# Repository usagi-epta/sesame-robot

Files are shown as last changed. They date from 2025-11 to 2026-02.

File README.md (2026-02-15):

# The Sesame Robot Project 
___







sesame-cover

___

**Greetings, from your new best friend.**

Sesame is an accessible Open-Source robotics project based on the ESP32 microcontroller system, with an emphasis on expression and movement. 
This project is designed for makers and engineers of all skill levels! Sesame offers a dynamic platform designed to start working with walking robots. 
To build a sesame robot, you will need basic soldering skills, $50-60 in hardware components, access to a 3D printer, and a basic understanding of Arduino IDE.

This repository contains the CAD design files, STL files, build and wiring guides, and the base/expanded firmware for the ESP32-based controller. 
There is also some included debugging firmware that may be helpful in getting your Sesame up and running.

## Features

*   **Quadruped Design:** Uses 8 servo motors (2 per leg) to achieve roughly 8 total degrees of freedom.
*   **Emotive Display:** Features a 128x64 OLED screen acting as a reactive face that syncs with movement.
*   **Fully Printable:** Designed entirely for 3D printing in PLA with minimal supports.
*   **Network Connectivity:** Connect to your WiFi network for remote control and API access.
*   **JSON API:** RESTful API for programmatic control from Python, JavaScript, and more.
*   **Conversational Faces:** Expressive emotion library with talk variants for voice assistant projects.
*   **Sesame Studio:** New animation composer software to easily create custom movements.
*   **Sesame Companion App:** Python application for voice control and advanced interactions.
*   **Serial CLI:** Control the robot and trigger animations via a Serial Command Line Interface or the web UI.
*   **Pre-programmed Emotes:** Includes animations for Walking, Waving, Dancing, Pointing, Resting, and more.

## Watch the launch video on YouTube

<a href="https://www.youtube.com/watch?v=1UDsWkcQZhc">thumb-youtube</a>

___

## Getting Started

Follow these steps to build your own Sesame Robot:

### 1. Gather Parts 
Check the **[Bill of Materials (BOM)](hardware/bom/README.md)** for a complete list of required electronics and hardware.
*   Microcontroller: Lolin S2 Mini (recommended for DIY builds), Sesame Distro Board V2 (included in Build Kits, pre-flashed), or ESP32-DevKitC-32E with Distro Board V1 (legacy)
*   Actuators: 8x MG90 Servos
*   Power: 5V 3A source (USB-C PD for S2 Mini and V2 Distro Board, or battery + buck converter; see BOM for the 2× 10440 Li-ion + 2× AAA holder option)

### 2. Print Parts 
Download the STLs and follow the **[Printing Guide](hardware/printing/README.md)**.
*   Designed for PLA
*   Minimal supports required

### 3. Build & Wire 
Follow the **[Build Guide](docs/build-guide/README.md)** and **[Wiring Guide](docs/wiring-guide/README.md)** to assemble the frame and connect the electronics.

### 4. Flash Firmware 
Upload the code from the **[Firmware Directory](firmware/README.md)**.
*   Requires Arduino IDE
*   Configure WiFi AP settings

### 5. Create Animations 
Use **[Sesame Studio](software/sesame-studio/README.md)** to visually design poses and sequences for your robot.

sesame-wakeup-gif

---

## Software & Firmware

### Sesame Studio
Sesame Studio is a standalone desktop application included in `software/sesame-studio/`. It allows you to:
*   Visually pose the robot using a schematic interface.
*   Generate C++ code for servo angles automatically.
*   Sequence frames into complex animations.

[**> Go to Sesame Studio**](software/sesame-studio/README.md)

sesamestudio-preview

### Sesame Companion App
The Sesame Companion App is a Python-based application that enables advanced control and interaction with your robot over your local network. It leverages the new JSON API and network mode features to provide:
*   **Voice Assistant Integration:** Control Sesame with voice commands and see real-time emotional expressions.
*   **Remote Control:** Command your robot from anywhere on your local network.
*   **Face Control:** Change expressions dynamically based on conversation or context.
*   **API Examples:** Reference implementation for building your own integrations.

The Companion App works with robots running the latest firmware with network mode enabled.

[**> Go to Sesame Companion App Repository**](https://github.com/dorianborian/sesame-companion-app)

### Firmware
The ESP32 firmware (`sesame-firmware-main.ino`) handles the kinematics, face display, and WiFi control interface.
*   **Web UI:** Control the robot from your phone via the built-in Access Point.
*   **Custom Faces:** Add your own bitmaps (guide in firmware docs).

[**> Go to Firmware Docs**](firmware/README.md)

firmware-preview

---

## Contributing

This robot is a platform for building new features, cosmetics, tools, and ideas. Since the current firmware is a basic implementation, pull requests are very welcome for:
*   Kinematics improvements
*   New animations
*   Improved Web UI/UX
*   Sensor integration (Ultrasonic, Gyro, etc.)

I would also love to see forks of this project with new hardware, software, faces, etc. Be sure to send me a message if you end up building one, and I might feature you on my website or channel!
  
---

## Sesame Complete Build Kit Pre-orders available!
I am excited to announce that, after popular demand, Sesame Complete Build Kits are now available for pre-order! 

That's right, your little robot companion just got even easier to build. Each kit includes all the components you need to build a full Sesame Robot. With the included detailed instructions, guides, and resources, this kit is perfect for both seasoned Makers and beginners. Click the image below to learn more.

<a href="https://www.doriantodd.com/sesame/kit">kits-availible</a>

---

*Created by [Dorian Todd](https://www.doriantodd.com/). Need help with your Sesame Robot? Send me a message on Discord, my username is "starphee"*

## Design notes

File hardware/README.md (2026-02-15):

# Hardware

All mechanical and electrical source files for the Sesame Robot live here. The hardware stack supports multiple build paths:

- **Hand-wired / Lolin S2 Mini build** for simple protoboard construction (recommended for DIY builds).
- **Custom Sesame Distro Board V2 build** for a professional SMD design with PD and battery support (included in Sesame Build Kits, pre-flashed).
- **Custom Sesame Distro Board V1 build** (legacy) for ESP32-DevKitC-32E stackup (phased out but still supported).

Use the sections below to jump to the files that match the version you are assembling.

## Directory Guide

| Folder | What you will find |
| --- | --- |
| [bom](bom/README.md) | Full bill of materials covering both wiring approaches, plus power budget notes and links back to the build tutorial. Start here to gather every component before printing or soldering. |
| [cad](cad/README.md) | Parametric STEP and Fusion 360 source models for every printed part. Great for remixing joint geometry or adapting the shell—just note the caution about features that may not translate across CAD packages. |
| [pcb](pcb/README.md) | Sesame Distro Board V2 (current) and V1 (legacy) schematics, layout files, Gerber files, BOM, and Pick-and-Place files. Includes ordering instructions for PCBway fabrication and assembly services. |
| [printing](printing/README.md) | Practical PLA print settings, support callouts, and image references for joint orientation and the top cover’s manual supports. |

## Getting Started

1. **Decide on a wiring strategy.** Review the comparison section in [docs/wiring-guide/README.md](../docs/wiring-guide/README.md) to choose between the protoboard and custom PCB routes. The Lolin S2 Mini build is recommended for DIY builders. If you have a Sesame Build Kit, your V2 Distro Board is already pre-flashed and ready to use.
2. **Print the shell and joints.** Follow the presets in [printing/README.md](printing/README.md) to prep the 3D files from `hardware/printing/stl`.
3. **Source electronics.** Use the line-by-line list in [bom/README.md](bom/README.md) and verify your power supply meets the 5V/3A requirement.
4. **Assemble electronics.** Reference either the hand-wiring steps or the appropriate Distro Board guide plus the wiring diagrams in `docs/wiring-guide/`.

> [!TIP]
> Keep photos of your wiring progress. They are invaluable for troubleshooting later and help when sharing build notes with the community.

## Supporting Documents

- [docs/build-guide/README.md](../docs/build-guide/README.md) for end-to-end assembly sequencing.
- [docs/wiring-guide/README.md](../docs/wiring-guide/README.md) for wiring diagrams, safety notes, and packing tips.

Improvements, remixes, and test reports are welcome, file issues or PRs with any updates you discover while building. <3

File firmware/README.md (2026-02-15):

# Sesame Robot Firmware

This document provides technical information on the firmware architecture, control logic, and hardware abstraction layers used in the Sesame Robot.

>[!NOTE]
> The firmware is now organized into a modular structure with a main entry point and specialized header files for bitmaps, movement, and web assets. This makes customization much easier and the codebase cleaner.

## Table of Contents

- [How to Flash the Firmware](#how-to-flash-the-firmware)
- [Network Configuration](#network-configuration--connectivity)
- [API Reference](#api-reference)
  - [Legacy Web Endpoints](#legacy-web-endpoints)
  - [JSON API](#json-api-recommended-for-network-clients)
  - [Python Examples](#python-api-example)
  - [JavaScript Examples](#nodejsjavascript-example)
- [Advanced Integration Examples](#advanced-integration-examples)
  - [Voice Assistant Integration](#voice-assistant-integration)
  - [Home Automation](#home-automation-integration)
- [Idle Animation System](#idle-animation-system)
- [Firmware Architecture](#firmware-architecture)
- [Technical Implementation](#technical-implementation-overview)
- [Asset Pipeline & Face Customization](#asset-pipeline--face-customization)
- [Hardware Abstraction Layer](#hardware-abstraction-layer-hal)

## How to Flash the Firmware

> [!NOTE]
> **Sesame Build Kit Users:** Your Distro Board V2 comes pre-flashed with the latest firmware. You only need to flash firmware if you want to customize it or update to a newer version.

### Prerequisites
1. **Arduino IDE** (version 2.0 or higher recommended)
2. **ESP32 Board Support**: Install via Arduino IDE's Board Manager
   - Open Arduino IDE
   - Go to **File → Preferences**
   - Add to "Additional Board Manager URLs": `https://raw.githubusercontent.com/espressif/arduino-esp32/gh-pages/package_esp32_index.json`
   - Go to **Tools → Board → Boards Manager**
   - Search for "ESP32" and install "ESP32 by Espressif Systems" (v2.0.0 or higher)
3. **Required Libraries** (install via Library Manager):
   - `ESP32Servo`
   - `Adafruit SSD1306`
   - `Adafruit GFX Library`

### Flashing Steps
1. **Connect your board** via USB to your computer
2. **Open the firmware**:
   - Open [sesame-firmware-main.ino](sesame-firmware-main.ino) in Arduino IDE
   - Make sure you have it in a folder with the same name.
   - Also include all of the .h header files.
3. **Select your board**:
   - Go to **Tools → Board**
   - For Lolin S2 Mini: Select "LOLIN S2 Mini"
   - For Sesame Distro Board V1 or V2: Select "ESP32 Dev Module"
4. **Configure board settings** (if using Lolin S2 Mini):
   - **Upload Speed**: 921600
   - **USB CDC On Boot**: "Enabled"
   - **Partition Scheme**: "Default 4MB with spiffs"
5. **Select the correct port**:
   - Go to **Tools → Port** and select your ESP32's COM port
6. **Choose your board configuration** in the code:
   - Open [sesame-firmware-main.ino](sesame-firmware-main.ino)
   - Find the pin configuration section (around line 55-65)
   - **If you built with the Lolin S2 Mini:** Uncomment the S2 Mini `servoPins` array and `I2C_SDA`/`I2C_SCL` defines. Comment out the Distro Board section.
   - **If you built with the Distro Board V1 or V2 and ESP32-DevKitC-32E:** Uncomment the Distro Board `servoPins` array and `I2C_SDA`/`I2C_SCL` defines. Comment out the S2 Mini section. (V1 and V2 use the same pin configuration)
7. **(Optional) Configure network mode**:
   - If you want the robot to connect to your WiFi network (for API access and remote control), edit the network configuration section (around line 17-22):
   ```cpp
   #define NETWORK_SSID "YourNetworkName"  // Your WiFi network name
   #define NETWORK_PASS "YourPassword"     // Your WiFi password
   #define ENABLE_NETWORK_MODE true        // Set to true to enable
   ```
   - Leave `ENABLE_NETWORK_MODE false` to use Access Point mode only
8. **Upload the firmware**:
   - Click the **Upload** button (→) in Arduino IDE
   - Wait for compilation and upload to complete
9. **Test the connection**:
   - Open Serial Monitor (**Tools → Serial Monitor**, set baud rate to 115200)
   - Reset the board - you should see startup messages and network information
   - The serial monitor provides individual motor control for testing and troubleshooting
   - **If using AP mode only**: Connect to the "Sesame-Controller-BETA" WiFi network (password: `12345678`) and navigate to any website
   - **If using network mode**: Look for the "Connected to network!" message in Serial Monitor, then access via `http://sesame-robot.local` or the displayed IP address

### Troubleshooting
- **Upload fails**: Try holding the BOOT button while uploading, or try a different USB cable
- **Port not found**: Install the appropriate USB drivers (CP210x for S2 Mini, CH340 for some ESP32 boards)
- **Compilation errors**: Verify all required libraries are installed
- **Robot not moving**: Check power supply and servo connections; increase `motorCurrentDelay` in web settings if brownouts occur
- **Can't connect to network**: 
  - Verify `ENABLE_NETWORK_MODE` is set to `true` and SSID/password are correct
  - Check Serial Monitor for connection status - look for "Connected to network!" or error messages
  - Ensure your WiFi network is 2.4GHz (ESP32 does not support 5GHz)
  - Try increasing the connection timeout in the code (currently 10 seconds / 20 attempts)
- **mDNS hostname not resolving**:
  - On Windows, install [Bonjour Print Services](https://support.apple.com/kb/DL999)
  - On Linux, ensure `avahi-daemon` is installed and running
  - Try accessing via IP address instead (check Serial Monitor for the assigned IP)
  - Some routers block mDNS traffic - check router settings or use IP address
- **API commands not working**:
  - Ensure you're sending POST requests to `/api/command` (not GET)
  - Verify `Content-Type: application/json` header is set
  - Check Serial Monitor for error messages and parsed command output
  - Test with a simple cURL command first to verify connectivity

## Firmware Architecture

The firmware is split into several key files to keep the logic organized and assets easy to manage:

- **[sesame-firmware-main.ino](sesame-firmware-main.ino)**: The main entry point containing the `setup()`, `loop()`, core system logic, network configuration, and API endpoints.
- **[face-bitmaps.h](face-bitmaps.h)**: A dedicated header for OLED face macros and raw bitmap data. Now includes extensive conversational faces for voice assistant integration.
- **[movement-sequences.h](movement-sequences.h)**: Definitions for all procedural movement and pose animations.
- **[captive-portal.h](captive-portal.h)**: Contains the HTML, CSS, and JS for the web-based remote control interface.

## Technical Implementation Overview

The firmware is built on the Arduino-ESP32 framework. Currently the firmware is running on a single-core event loop, and hardware-based PWM timers for precise motor control.

### PWM & Servo Kinematics
- **Timer Allocation**: The firmware uses `ESP32PWM::allocateTimer(n)` to reserve hardware timers 0-3. This prevents conflicts with other peripherals and ensuring high-resolution PWM signals (50Hz frequency). Due to the limited number of timers, you may experience network errors upon adding additional devices or calls to the firmware. For example, in a modded version of the robot, I tried adding two ESCs and their servo controll to the code, and the CPU ran out of internal timers and caused the captive portal to die. If you are experiencing network errors with your custom firmware, check the timer allocation.
- **Pulse Width Mapping**: Leg servos are mapped from degrees (0-180) to microseconds (732us to 2929us). This range is set to the maximum travel on most hobby servos with a 180 degree limit, but can be edited in the `servos[i].attach()` calls. If you are using motors with a larger range of motion, like 270 degree servos, you need to set the PWM mapping to a different length of microseconds. For 270 degree servos specifically I found (833us to 2167us) works.
- **Staggered Activation**: To prevent VCC rail collapse (brownout) caused by simultaneous inductive loads, the `setServoAngle` helper introduces a mandatory `motorCurrentDelay` (default 20ms) between sequential pulses. This delay should be tweaked to your power setup. If you have a strong dedicated power supply you can try setting it to zero. It can also be changed while running through the AP controller settings menu.

### Communication & Networking Stack
- **Dual-Mode WiFi**: The ESP32 can simultaneously operate in both Access Point mode (for direct connections) and Station mode (connected to an existing network) using `WiFi.mode(WIFI_AP_STA)`.
- **SoftAP & Captive Portal**: The ESP32 initializes an Access Point using `WiFi.softAP()`. A `DNSServer` listens on UDP Port 53, using a wildcard "*" redirect to map all DNS queries to the internal gateway (`192.168.4.1`).
- **mDNS Service Discovery**: The firmware broadcasts `sesame-robot.local` via Multicast DNS (mDNS) using the `ESPmDNS` library, allowing network discovery without hardcoded IP addresses.
- **RESTful API Surface**: The `WebServer` handles both legacy URL-parameter endpoints and modern JSON-based API:
  - `/cmd?go=[dir]`: Legacy movement control
  - `/cmd?pose=[name]`: Legacy pose triggers
  - `/api/status`: JSON status endpoint (GET)
  - `/api/command`: JSON command endpoint (POST) - supports face-only updates and combined face+movement commands
  - `/getSettings` / `/setSettings`: Parameter configuration
- **Face-Only Command Support**: The `/api/command` endpoint intelligently detects face-only requests (no `command` field) and updates the display without triggering movement animations.
- **Non-Blocking Control Flow**: Instead of `delay()`, the firmware uses a custom `pressingCheck(String cmd, int ms)` function. This function polls `server.handleClient()` and `dnsServer.processNextRequest()` during animation frames, allowing for real-time interruptibility (e.g., immediate stop on button release). This pressingCheck protocol can be used for motion commands like walking to play each motion only when the button is held.

### Display & Graphics Subsystem
- **I2C Bus Hardware**: Utilizes the ESP32's hardware I2C controller at 400kHz (Fast Mode) for minimal latency when pushing full-frame buffers to the SSD1306 display.
- **Memory Management (`PROGMEM`)**: Large 128x64 bitmap arrays (1024 bytes per frame) are stored in Flash memory using the `PROGMEM` attribute.
- **Macro-Based Asset Management**: The firmware uses a `FACE_LIST` macro in [face-bitmaps.h](face-bitmaps.h) to automatically register and handle new faces, reducing the boilerplate required when adding animations.
- **Rendering Pipeline**: The `updateAnimatedFace()` function manages frame rates and sequence looping outside of the main movement logic to ensure smooth visual feedback even during complex movements.
- **Dynamic WiFi Info Overlay**: The `updateWifiInfoScroll()` function composites scrolling connection information over the face bitmap during the first 30 seconds of operation (before first input), drawing the face as background with a black bar and white text overlay for readability.
- **Idle Animation System**: Implements realistic idle behavior with randomized blinking (including double-blinks) and boomerang face animations, triggered automatically when no input is detected.

## Prerequisites & Development Environment

- **Board Support**: ESP32 by Espressif Systems (v2.0.0+ recommended). Lolin S2 Mini and ESP32-WROOM32 DevKitC are best supported.
- **Libraries**:
  - `ESP32Servo`: Low-level PWM timer management.
  - `Adafruit_SSD1306` & `Adafruit_GFX`: Buffer-based OLED rendering.
  - `ESPmDNS`: mDNS service discovery (included with ESP32 board support).
  - `DNSServer`: Captive portal DNS redirection (included with ESP32 board support).
  - `WebServer`: HTTP server implementation (included with ESP32 board support).
- **Tooling**: Arduino IDE 2.0+ recommended.

## Network Configuration & Connectivity

The firmware now supports **dual-mode WiFi operation**, allowing the robot to simultaneously act as an Access Point (for direct connections) and connect to your existing WiFi network (for integration with other devices and remote control).

### Access Point Mode (Default)
By default, the robot creates its own WiFi network:
- **SSID**: `Sesame-Controller-BETA`
- **Password**: `12345678`
- **IP Address**: `192.168.4.1`

Connect to this network and navigate to any website to access the captive portal control interface.

### Network Mode (Optional)
To connect the robot to your home or office WiFi network:

1. **Enable Network Mode** in [sesame-firmware-main.ino](sesame-firmware-main.ino):
   ```cpp
   #define NETWORK_SSID "YourNetworkName"  // Your WiFi network name
   #define NETWORK_PASS "YourPassword"     // Your WiFi password
   #define ENABLE_NETWORK_MODE true        // Set to true to enable
   ```

2. **Flash the updated firmware** to your robot.

3. **Access via multiple methods**:
   - **mDNS Hostname**: `http://sesame-robot.local` (works on most devices)
   - **Network IP**: Check Serial Monitor at 115200 baud for the assigned IP address
   - **Still accessible via AP**: The robot maintains its Access Point even when connected to your network

### mDNS Discovery
The firmware includes an mDNS responder that broadcasts the hostname `sesame-robot.local` on your local network. This allows you to access the robot without knowing its IP address:

```bash
# Access from browser
http://sesame-robot.local

# Ping test
ping sesame-robot.local
```

**Note**: mDNS works natively on:
- macOS and iOS devices
- Linux with Avahi installed
- Windows 10+ (may require Bonjour service)

### Security Considerations

The firmware is designed for local network use and does not include authentication by default. When enabling network mode:

- **Local Network Only**: The robot responds to requests from any device on your network. Do not expose it to the internet without proper security measures.
- **No HTTPS**: Communication is unencrypted HTTP. Avoid transmitting sensitive data through the robot's API.
- **Access Point Password**: The default AP password is `12345678`. For production use, change `AP_PASS` in the firmware to a stronger password.
- **Trusted Networks**: Only connect your robot to trusted WiFi networks.

For enhanced security:
1. Change the default AP password to a strong, unique password
2. Use network segmentation (IoT VLAN) to isolate the robot from critical devices
3. Implement firewall rules to restrict access to specific IP addresses
4. Consider adding authentication headers in a custom firmware fork for production deployments

### WiFi Information Display
The robot's OLED screen now features an intelligent WiFi info system:
- **First 30 seconds**: If no input is received, WiFi connection information scrolls across the top of the display
- **After first input**: WiFi info disappears to show only faces
- **Dual-mode info**: When connected to both AP and network, displays both connection details

The scrolling text includes:
- Access Point SSID and IP
- Network name and IP (if connected)
- mDNS hostname
- Captive portal instructions

## API Reference

The firmware exposes both legacy web endpoints and a modern JSON-based API for programmatic control.

### Legacy Web Endpoints

These endpoints use URL parameters and are primarily used by the web interface:

#### Movement Control
```http
GET /cmd?go=forward
GET /cmd?go=backward
GET /cmd?go=left
GET /cmd?go=right
GET /cmd?stop
```

#### Pose Control
```http
GET /cmd?pose=wave
GET /cmd?pose=dance
GET /cmd?pose=rest
GET /cmd?pose=stand
# ... (see movement-sequences.h for all available poses)
```

#### Individual Motor Control
```http
GET /cmd?motor=1&value=90
# motor: 1-8 (motor number)
# value: 0-180 (angle in degrees)
```

#### Settings Management
```http
GET /getSettings
# Returns: {"frameDelay":100,"walkCycles":10,"motorCurrentDelay":20,"faceFps":8}

GET /setSettings?frameDelay=120&walkCycles=15&motorCurrentDelay=25&faceFps=10
```

### JSON API (Recommended for Network Clients)

The JSON API is designed for programmatic control from external devices, Python scripts, and IoT integrations.

#### Get Robot Status
```http
GET /api/status
```

**Response:**
```json
{
  "currentCommand": "forward",
  "currentFace": "walk",
  "networkConnected": true,
  "apIP": "192.168.4.1",
  "networkIP": "192.168.1.100"
}
```

#### Send Commands
```http
POST /api/command
Content-Type: application/json

{
  "command": "forward",
  "face": "walk"
}
```

**Response:**
```json
{
  "status": "ok",
  "message": "Command executed"
}
```

#### Face-Only Updates
Send a face change without triggering movement:

```http
POST /api/command
Content-Type: application/json

{
  "face": "happy"
}
```

**Response:**
```json
{
  "status": "ok",
  "message": "Face updated"
}
```

#### Stop Command
```http
POST /api/command
Content-Type: application/json

{
  "command": "stop"
}
```

### Available Commands

**Movement Commands:**
- `forward`, `backward`, `left`, `right` - Continuous movement (loops until stopped)
- `stop` - Immediately stop current movement

**Pose Commands (one-shot animations):**
- `rest`, `stand`, `wave`, `dance`, `swim`, `point`
- `pushup`, `bow`, `cute`, `freaky`, `worm`, `shake`
- `shrug`, `dead`, `crab`

**Available Faces:**
- Movement faces: `walk`, `rest`, `stand`, `dance`, `wave`, etc.
- Conversational faces: `happy`, `sad`, `angry`, `surprised`, `sleepy`, `love`, `excited`, `confused`, `thinking`
- Talk variants: `talk_happy`, `talk_sad`, `talk_angry`, etc.
- Special: `idle`, `idle_blink`, `default`

### Python API Example

```python
import requests
import time

# Robot IP or hostname
robot_url = "http://sesame-robot.local"

# Get status
response = requests.get(f"{robot_url}/api/status")
status = response.json()
print(f"Current face: {status['currentFace']}")

# Make robot wave and show happy face
requests.post(f"{robot_url}/api/command", json={
    "command": "wave",
    "face": "happy"
})

time.sleep(3)

# Just change face without moving
requests.post(f"{robot_url}/api/command", json={
    "face": "excited"
})

# Stop movement
requests.post(f"{robot_url}/api/command", json={
    "command": "stop"
})
```

### cURL Examples

```bash
# Get robot status
curl http://sesame-robot.local/api/status

# Make robot dance
curl -X POST http://sesame-robot.local/api/command \
  -H "Content-Type: application/json" \
  -d '{"command":"dance","face":"dance"}'

# Change face only
curl -X POST http://sesame-robot.local/api/command \
  -H "Content-Type: application/json" \
  -d '{"face":"happy"}'

# Stop movement
curl -X POST http://sesame-robot.local/api/command \
  -H "Content-Type: application/json" \
  -d '{"command":"stop"}'
```

### Node.js/JavaScript Example

```javascript
const robotURL = 'http://sesame-robot.local';

// Get status
fetch(`${robotURL}/api/status`)
  .then(res => res.json())
  .then(data => console.log('Robot status:', data));

// Send command
fetch(`${robotURL}/api/command`, {
  method: 'POST',
  headers: {'Content-Type': 'application/json'},
  body: JSON.stringify({
    command: 'wave',
    face: 'happy'
  })
})
.then(res => res.json())
.then(data => console.log('Response:', data));

// Face-only update
fetch(`${robotURL}/api/command`, {
  method: 'POST',
  headers: {'Content-Type': 'application/json'},
  body: JSON.stringify({face: 'surprised'})
})
.then(res => res.json())
.then(data => console.log('Response:', data));
```

## Advanced Integration Examples

### Voice Assistant Integration

The combination of conversational faces, the JSON API, and network mode makes the Sesame Robot perfect for voice assistant projects. Here's an example using Python with speech recognition:

```python
import requests
import speech_recognition as sr
from textblob import TextBlob
import time

robot_url = "http://sesame-robot.local"

def analyze_sentiment(text):
    """Analyze sentiment and return appropriate face"""
    blob = TextBlob(text)
    polarity = blob.sentiment.polarity
    
    if polarity > 0.5:
        return "excited"
    elif polarity > 0.2:
        return "happy"
    elif polarity < -0.5:
        return "angry"
    elif polarity < -0.2:
        return "sad"
    else:
        return "thinking"

def set_robot_face(face, talking=False):
    """Update robot's face expression"""
    if talking:
        face = f"talk_{face}"
    
    requests.post(f"{robot_url}/api/command", json={"face": face})

# Initialize speech recognition
recognizer = sr.Recognizer()

while True:
    with sr.Microphone() as source:
        print("Listening...")
        set_robot_face("idle")
        
        try:
            audio = recognizer.listen(source, timeout=5)
            set_robot_face("thinking")
            
            text = recognizer.recognize_google(audio)
            print(f"You said: {text}")
            
            # Determine emotion and show talking face
            emotion = analyze_sentiment(text)
            set_robot_face(emotion, talking=True)
            
            # Process command...
            time.sleep(2)
            
            # Return to neutral
            set_robot_face(emotion, talking=False)
            
        except sr.WaitTimeoutError:
            set_robot_face("sleepy")
        except sr.UnknownValueError:
            set_robot_face("confused")
```

### Home Automation Integration

Integrate with Home Assistant or other home automation platforms:

```python
# Home Assistant automation example
import requests

def robot_notification(message_type):
    """Display robot emotion based on notification type"""
    robot_url = "http://sesame-robot.local"
    
    emotion_map = {
        "doorbell": "surprised",
        "alarm": "angry",
        "reminder": "thinking",
        "success": "happy",
        "error": "sad"
    }
    
    face = emotion_map.get(message_type, "default")
    requests.post(f"{robot_url}/api/command", json={"face": face})
    
    # Optional: add movement
    if message_type == "doorbell":
        requests.post(f"{robot_url}/api/command", json={
            "command": "wave",
            "face": "happy"
        })
```

### WebSocket Streaming (Advanced)

For real-time control with minimal latency, you can poll the status endpoint or implement a simple state machine:

```javascript
// React/Vue.js real-time robot control
class RobotController {
  constructor(robotURL) {
    this.url = robotURL;
    this.currentFace = 'default';
  }
  
  async updateEmotion(emotion, isSpeaking) {
    const face = isSpeaking ? `talk_${emotion}` : emotion;
    
    if (face !== this.currentFace) {
      await fetch(`${this.url}/api/command`, {
        method: 'POST',
        headers: {'Content-Type': 'application/json'},
        body: JSON.stringify({face})
      });
      
      this.currentFace = face;
    }
  }
  
  async getStatus() {
    const res = await fetch(`${this.url}/api/status`);
    return await res.json();
  }
  
  async performAction(action, emotion = null) {
    const payload = {command: action};
    if (emotion) payload.face = emotion;
    
    await fetch(`${this.url}/api/command`, {
      method: 'POST',
      headers: {'Content-Type': 'application/json'},
      body: JSON.stringify(payload)
    });
  }
}

// Usage
const robot = new RobotController('http://sesame-robot.local');

// Set emotion without moving
await robot.updateEmotion('happy', false);

// Set talking face
await robot.updateEmotion('excited', true);

// Perform action with face
await robot.performAction('dance', 'excited');

// Check status
const status = await robot.getStatus();
console.log(`Robot is ${status.currentFace} and doing ${status.currentCommand}`);
```

## Idle Animation System

The firmware includes an intelligent idle animation system that activates automatically:

### Behavior
- **Activation**: When the robot has received no commands for a period, it enters idle mode
- **Idle Face**: Displays a gentle "breathing" animation using the `idle` face in `FACE_ANIM_BOOMERANG` mode
- **Blinking**: Randomly triggers blink animations (3-7 second intervals)
- **Double Blinks**: 30% chance of a double blink for realistic behavior
- **Exit**: Any movement command or input immediately exits idle mode

### Technical Implementation
The idle system uses:
- `enterIdle()` - Activates idle face with boomerang animation
- `exitIdle()` - Returns to normal operation
- `updateIdleBlink()` - Manages random blink timing and double-blink logic
- `scheduleNextIdleBlink()` - Randomizes blink intervals for natural appearance

To customize idle behavior, modify the timing values in [sesame-firmware-main.ino](sesame-firmware-main.ino):
```cpp
scheduleNextIdleBlink(3000, 7000);  // Min and max ms between blinks
```

## Asset Pipeline & Face Customization

The firmware includes an intelligent idle animation system that activates automatically:

### Behavior
- **Activation**: When the robot has received no commands for a period, it enters idle mode
- **Idle Face**: Displays a gentle "breathing" animation using the `idle` face in `FACE_ANIM_BOOMERANG` mode
- **Blinking**: Randomly triggers blink animations (3-7 second intervals)
- **Double Blinks**: 30% chance of a double blink for realistic behavior
- **Exit**: Any movement command or input immediately exits idle mode

### Technical Implementation
The idle system uses:
- `enterIdle()` - Activates idle face with boomerang animation
- `exitIdle()` - Returns to normal operation
- `updateIdleBlink()` - Manages random blink timing and double-blink logic
- `scheduleNextIdleBlink()` - Randomizes blink intervals for natural appearance

To customize idle behavior, modify the timing values in [sesame-firmware-main.ino](sesame-firmware-main.ino):
```cpp
scheduleNextIdleBlink(3000, 7000);  // Min and max ms between blinks
```

## Hardware Abstraction Layer (HAL)

The firmware abstracts pin definitions via the `servoPins` array. The default configuration is optimized for the **Sesame Distro Board V1/V2** and **Lolin S2 Mini**, but is easily portable to any ESP32 with WiFi capability (e.g., S3, C3, or DevKit V1).

### Pin Configuration Tables

#### Lolin S2 Mini (ESP32-S2)

| Motor/Component | Array Index | GPIO Pin | Notes |
|---|---|---|---|
| Motor 0 | 0 | 1 | R1 |
| Motor 1 | 1 | 2 | R2 |
| Motor 2 | 2 | 4 | L1 |
| Motor 3 | 3 | 6 | L2 |
| Motor 4 | 4 | 8 | R4 |
| Motor 5 | 5 | 10 | R3 |
| Motor 6 | 6 | 13 | L3 |
| Motor 7 | 7 | 14 | L4 |
| **I2C SDA** | - | **33** | SSD1306 Data (Hardware I2C) |
| **I2C SCL** | - | **35** | SSD1306 Clock (Hardware I2C) |

#### Sesame Distro Board V1 & V2 (ESP32-WROOM32)

> [!NOTE]
> Both V1 and V2 Distro Boards use the same pin configuration.

| Motor/Component | Array Index | GPIO Pin | Notes |
|---|---|---|---|
| Motor 0 | 0 | 15 | R1 |
| Motor 1 | 1 | 2 | R2 |
| Motor 2 | 2 | 23 | L1 |
| Motor 3 | 3 | 19 | L2 |
| Motor 4 | 4 | 4 | R4 |
| Motor 5 | 5 | 16 | R3 |
| Motor 6 | 6 | 17 | L3 |
| Motor 7 | 7 | 18 | L4 |
| **I2C SDA** | - | **21** | SSD1306 Data (Hardware I2C) |
| **I2C SCL** | - | **22** | SSD1306 Clock (Hardware I2C) |

### Porting to Other ESP32 Variants

To port this to a different ESP32 variant, modify the `servoPins` and `I2C_` defines in the header of [sesame-firmware-main.ino](sesame-firmware-main.ino). Ensure the chosen pins are PWM-capable and not "input-only".

## Asset Pipeline & Face Customization

To maintain a clean main source file and optimize performance, face bitmaps are decoupled from the primary logic. Faces are managed in [face-bitmaps.h](face-bitmaps.h) using a "Single Source of Truth" macro system.

### Face Library

The firmware includes an extensive library of faces organized into three categories:

#### Movement Faces
Synchronized with physical poses and animations:
- `walk`, `rest`, `stand`, `swim`, `dance`, `wave`, `point`
- `pushup`, `bow`, `cute`, `freaky`, `worm`, `shake`, `shrug`
- `dead`, `crab`, `idle`, `idle_blink`

#### Conversational Faces
Designed for expressive communication and voice assistant integration:
- **Base emotions**: `happy`, `sad`, `angry`, `surprised`, `sleepy`, `love`, `excited`, `confused`, `thinking`
- **Talk variants**: `talk_happy`, `talk_sad`, `talk_angry`, `talk_surprised`, `talk_sleepy`, `talk_love`, `talk_excited`, `talk_confused`, `talk_thinking`

The "talk_" variants feature open mouths for lip-sync and animated speech. These faces are perfect for:
- Voice assistant projects (Alexa, Google Assistant, custom TTS)
- Chatbot interfaces controlled via the JSON API
- Interactive storytelling and educational applications
- Remote-controlled performances

#### Special Faces
- `default` - The startup/fallback face
- `idle` - Gentle breathing animation for idle state
- `idle_blink` - Blink animation triggered randomly during idle

### Adding Custom Faces

### Workflow:
1.  **Image Creation**: Find faces using Kaomoji or [Emojicombos](https://emojicombos.com/kaomoji). Create a `128x64` image in a tool like [jsPaint](https://jspaint.app/).
2.  **Bitmap Conversion**: Use [image2cpp](https://javl.github.io/image2cpp/) with `Horizontal` scaling, `128x64` resolution, and `Arduino Code` output.
3.  **Registration**:
    -   Add your face name to the `FACE_LIST` macro in [face-bitmaps.h](face-bitmaps.h).
    -   Paste the generated C array into [face-bitmaps.h](face-bitmaps.h) right after the last bitmap in the list.
    -   (Optional) For animations, add numbered suffixes (e.g., `_1`, `_2`) and register the FPS in the `faceFpsEntries` in [sesame-firmware-main.ino](sesame-firmware-main.ino).

### Animating Faces
For an animation to be recognized by the `MAKE_FACE_FRAMES` macro, your array names in [face-bitmaps.h](face-bitmaps.h) must follow a strict naming convention:
- **Root Frame**: `epd_bitmap_myface` (This is required and acts as frame 0).
- **Subsequent Frames**: `epd_bitmap_myface_1`, `epd_bitmap_myface_2`, etc.
- **Limit**: The default system supports up to 6 frames per face (Root + 5 numbered frames).
- **Animation Modes**: Animations can be configured to play as a `LOOP` (restarts at frame 0), `ONCE` (stops on the final frame), or `BOOMERANG` (plays forward then reverses). These modes are typically defined in [movement-sequences.h](movement-sequences.h) when triggerring a pose.

### Macro System
The `FACE_LIST` macro uses X-Macros to automatically generate variable declarations and registration objects:
```cpp
#define FACE_LIST \
    X(walk) \
    X(rest) \
    X(my_new_face) // Just add this line!
```
This eliminates the need to manually update multiple switch statements or arrays when adding new assets.

## Execution & Deployment

1.  **Toolchain**: Configure your IDE for `ESP32 Dev Module` or `Lolin S2 Mini`.
2.  **Calibration**: Use the Serial Monitor (115200) to send manual step commands (e.g., `rn wf`).
3.  **Power Management**: If the robot brownouts during movement, increase `motorCurrentDelay` in the web settings to further stagger servo bursts.

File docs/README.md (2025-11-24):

# Documentation

Documentation for the Sesame Robot project.

- **assembly/** - Assembly instructions
- **build-guide/** - Build guide with photos
- **images/** - Photos and diagrams
- **datasheets/** - Component datasheets

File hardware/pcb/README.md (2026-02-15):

# PCB Schematics

Electronic schematics and PCB designs for the Sesame Robot Project. There are two versions of the Sesame Distro Board available: V2 (current) and V1 (legacy).

> [!NOTE]
> **For Sesame Build Kits:** All Sesame Build Kits include a pre-flashed Sesame Distro Board V2, so you don't need to order or assemble a board separately.

> [!TIP]
> **Building from Scratch?** If you're building a Sesame Robot from scratch, we recommend using the **S2 Mini with hand wiring approach** for the easiest assembly experience. The V2 distro board uses advanced SMD components that require specialized soldering skills or PCB assembly services.

---

## Sesame Distro Board V2 (Current)

The **Sesame Distro Board V2** is the latest version and features:
- **Power Delivery (PD) support** - Works with USB-C PD power supplies
- **Battery power support** - Also works with battery power
- **Compact SMD design** - All surface-mount components for a professional finish
- **Included in all Sesame Build Kits** - Pre-flashed and ready to use

### Assembly Options for V2

The V2 board consists entirely of SMD (surface-mount) components, which are **advanced to hand solder**. We recommend:

1. **PCB Assembly Service (Recommended):** Use [PCBway's PCB assembly service](https://www.pcbway.com/pcb-assembly.html) to have the board professionally assembled. Upload the Gerber, BOM, and Pick-and-Place files to their assembly service.
2. **Hand Soldering (Advanced Only):** Only attempt hand soldering if you're experienced with SMD components and have the proper tools (hot air station, fine-tip soldering iron, flux, etc.).

### V2 Files Available

All files are located in the [`distro-v2/`](distro-v2/) directory:
- **Gerber file:** `Gerber_Sesame-Distro-V2_PCB.zip` - For PCB fabrication
- **BOM file:** `BOM_Sesame-Distro-V2.csv` - Bill of materials for SMD components
- **Pick-and-Place file:** `PickAndPlace_PCB_Sesame-Distro-V2.csv` - Component placement data for assembly

---

## Sesame Distro Board V1 (Legacy)

> [!CAUTION]  
> The Sesame Distro Board V1 is now **phased out** but still supported. V1 has some limitations: it won't run on tethered power (e.g., USB-C) and is harder to assemble than other options. V1 is still supported with wiring guides and firmware and works on battery power. If you have a V1 board, you can still use it successfully.

The Distro Board V1 pairs with the ESP32-DevKitC-32E.

> [!IMPORTANT]
> **ESP32 Pin Header Requirement:** The distro board V1 stacks on top of the ESP32-DevKitC-32E, so you need an ESP32 board **without pre-soldered pin headers**. If your board came with headers already soldered on the top, you will need to desolder all of the headers and flip them to the bottom side of the ESP32 board so the distro board can mount on top.

### V1 Board Schematic:

Schematic_Sesame-Distro-Board

### V1 Files Available

All files are located in the [`distro-v1/`](distro-v1/) directory.

---

## PCBway Sponsorship

**PCBway Sponsorship**

This project was sponsored by [PCBway](https://www.pcbway.com/), who manufactured the custom distro boards. PCBway offers high-quality PCB fabrication services with fast turnaround times and excellent customer support. 

If you're building your own Sesame Robot, PCBway is a great option for getting professional-quality PCB fabrication and assembly services at reasonable prices:
- **PCB Fabrication:** Upload Gerber files to get boards manufactured
- **PCB Assembly:** Upload Gerber, BOM, and Pick-and-Place files for fully assembled boards (recommended for V2)

pcbs-from-pcbway

---

## How to Order

### Ordering V2 Boards (Recommended)

**Option 1: PCB Assembly Service (Recommended)**

1. Go to [PCBway's PCB Assembly service](https://www.pcbway.com/pcb-assembly.html)
2. Upload the Gerber file: `distro-v2/Gerber_Sesame-Distro-V2_PCB.zip`
3. Upload the BOM file: `distro-v2/BOM_Sesame-Distro-V2.csv`
4. Upload the Pick-and-Place file: `distro-v2/PickAndPlace_PCB_Sesame-Distro-V2.csv`
5. Confirm board specifications and component availability
6. Place your order to receive fully assembled boards

**Option 2: Fabrication Only (For Advanced Users)**

1. Download the Gerber file from [`distro-v2/Gerber_Sesame-Distro-V2_PCB.zip`](distro-v2/Gerber_Sesame-Distro-V2_PCB.zip)
2. Upload to [PCBway](https://www.pcbway.com/) or another PCB manufacturer
3. Confirm board specifications in the preview
4. Order the bare PCBs and hand-solder SMD components yourself (advanced)

### Ordering V1 Boards (Legacy)

1. Download the Gerber file from [`distro-v1/Gerber_Sesame-Distro-Board_PCB_Sesame-Distro-Board_V1.zip`](distro-v1/Gerber_Sesame-Distro-Board_PCB_Sesame-Distro-Board_V1.zip)
2. Upload to [PCBway](https://www.pcbway.com/) or another PCB manufacturer
3. Confirm board specifications in the preview
4. Place your order to receive bare V1 boards

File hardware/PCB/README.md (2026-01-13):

# PCB Schematics

Electronic schematics and wiring diagrams for the Sesame Distro Board, a custom PCB just for the Sesame Robot Project. The distro boar pairs with the ESP32-DevKitC-32E.

**PCBway Sponsorship**

This project was sponsored by [PCBway](https://www.pcbway.com/), who manufactured the custom distro boards. PCBway offers high-quality PCB fabrication services with fast turnaround times and excellent customer support. You can order your own Sesame Distro Boards by uploading the Gerber files (found in the hardware section) to their website.

If you're building your own Sesame Robot, PCBway is a great option for getting professional-quality distro boards manufactured at reasonable prices.

pcbs-from-pcbway

## Board Schematic:

Schematic_Sesame-Distro-Board

### PCB Layout:
SDB-Layout

## How to order one:

1. Download the Gerber archive `Gerber_Sesame-Distro-Board_PCB_Sesame-Distro-Board_V1.zip` from this directory.
2. Upload that zip file to PCBway as the project Gerber bundle and confirm the board thickness and finish match the Sesame Distro Board requirements.
3. Double-check the provided drill, solder mask, and silkscreen layers in the preview before placing the order to ensure the traces and cutouts stay consistent with the schematic.
4. Specify the desired quantity and shipping options, then submit the order to receive professionally fabricated Sesame Distro Boards.

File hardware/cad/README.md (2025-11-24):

# CAD Files

3D CAD models and STL files for 3D printing the Sesame Robot body.

Print with PLA/PLA+ at 15-20% infill with minimal supports.

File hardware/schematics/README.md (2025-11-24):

# Schematics

Electronic schematics and wiring diagrams for the Sesame Robot.

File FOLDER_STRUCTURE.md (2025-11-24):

# Sesame Robot - Folder Structure

This document provides an overview of the Sesame Robot project folder structure.

## Directory Layout

```
sesame-robot/
├── hardware/                 # Hardware design files
│   ├── cad/                 # 3D CAD models and STL files for printing
│   ├── schematics/          # Electronic schematics and wiring diagrams
│   ├── pcb/                 # Custom PCB design files (optional)
│   ├── bom/                 # Bill of Materials spreadsheets
│   └── manufacturing/       # Manufacturing files (Gerbers, print profiles)
│
├── firmware/                # Robot control firmware
│   ├── arduino/             # Main Arduino firmware sketches
│   └── libraries/           # Custom Arduino libraries
│
├── software/                # Control and interface software
│   ├── web-ui/              # Web-based control interface
│   └── control-app/         # Desktop and mobile control applications
│
├── docs/                    # Documentation
│   ├── assembly/            # Step-by-step assembly instructions
│   ├── build-guide/         # Complete build guide with photos
│   ├── images/              # Photos, diagrams, and illustrations
│   └── datasheets/          # Component datasheets and specs
│
├── examples/                # Example code and projects
├── tests/                   # Test code and validation procedures
├── README.md                # Main project documentation
├── LICENSE                  # Apache License 2.0
└── CONTRIBUTING.md          # Contribution guidelines
```

## Key Directories

### Hardware (`/hardware/`)
Contains all physical design files including 3D models, electronic schematics, PCB designs, and manufacturing documentation. See `/hardware/README.md` for details.

### Firmware (`/firmware/`)
Arduino-based firmware for controlling servos, managing the OLED display, and handling animations. Includes custom libraries for robot-specific functions. See `/firmware/README.md` for setup instructions.

### Software (`/software/`)
Control software including web interfaces and desktop/mobile applications for robot control. See `/software/README.md` for development information.

### Documentation (`/docs/`)
Complete documentation including assembly instructions, build guides, images, and component datasheets. See `/docs/README.md` for documentation guidelines.

### Examples (`/examples/`)
Example code for custom animations, sensor integration, and alternative control methods. Great starting point for learning and customization.

### Tests (`/tests/`)
Test code and validation procedures for hardware, firmware, and integration testing.

## Adding New Content

When contributing to the project, place files in the appropriate directory:

- **3D models** → `hardware/cad/`
- **Circuit diagrams** → `hardware/schematics/`
- **Arduino code** → `firmware/arduino/`
- **Libraries** → `firmware/libraries/`
- **Web interface** → `software/web-ui/`
- **Assembly photos** → `docs/images/`
- **Build instructions** → `docs/assembly/` or `docs/build-guide/`
- **Example projects** → `examples/`
- **Test code** → `tests/`

Each directory contains a README.md file with specific guidelines and details.

## Best Practices

1. **Maintain structure** - Keep files organized in their proper directories
2. **Document changes** - Update README files when adding new content
3. **Use clear names** - Name files descriptively (e.g., `leg_assembly_step1.jpg`)
4. **Include sources** - Provide native CAD files along with exports
5. **Add examples** - Include usage examples for new features
6. **Write tests** - Add tests for firmware changes

## Getting Help

- Read the main [README.md](README.md) for project overview
- Check [CONTRIBUTING.md](CONTRIBUTING.md) for contribution guidelines
- Review directory-specific README files for detailed information
- Open an issue for questions or discussions

## Resources

- Build videos: [https://www.youtube.com/@DorianToddYT/](https://www.youtube.com/@DorianToddYT/)
- Issues and discussions: GitHub repository
- Community builds and modifications: Share your creations!

---

This structure follows Open Source Hardware Association (OSHWA) best practices to ensure the project remains accessible, maintainable, and easy to contribute to.

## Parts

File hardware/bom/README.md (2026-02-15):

# Bill of Materials

Every part required to assemble Sesame is cataloged here. Pick the wiring strategy that fits your parts bin, then follow the build flow in [docs/build-guide/README.md](../../docs/build-guide/README.md).

> [!NOTE]
> Amazon links below point to representative search results so you can choose local suppliers or equivalent listings. Pricing and availability change frequently. If you don't mind waiting shipping times you can also order direct from manufacturer for much lower rates.

## Core Electronics (Both Builds)

| Item | Qty | Notes | Amazon |
| --- | --- | --- | --- |
| MG90S all-metal micro servos | 8 (buy 10 for spares) | Primary hip/leg actuators; includes servo horns but keep extras | [link](https://www.amazon.com/s?k=mg90s+metal+gear+servo+pack+of+8) |
| 0.96" SSD1306 I2C OLED | 1 | 128x64 display that slides into the top cover slot | [link](https://www.amazon.com/s?k=0.96%22+I2C+OLED+SSD1306) |
| USB-C data/power cable | 1 | Needs to carry 5V/3A for flashing and tethered mode | [link](https://www.amazon.com/s?k=usb+c+cable+60w) |
| Rocker power switch (KDC1, panel mount) | 1 | Snaps into the top cover cutout | [link](https://www.amazon.com/s?k=kdc1+mini+rocker+switch+2+pin) |
| 22AWG silicone wire kit | 1 | Power/ground bus lines | [link](https://www.amazon.com/s?k=22awg+silicone+wire+kit) |
| 30AWG silicone wire kit | 1 | Signal leads and dense harnessing | [link](https://www.amazon.com/s?k=30awg+silicone+wire) |
| Heat-shrink assortment | 1 | Insulate OLED, switch, and battery joints | [link](https://www.amazon.com/s?k=heat+shrink+tubing+kit) |
| Small zip ties | 1 pack | Bundling wires inside the frame | [link](https://www.amazon.com/s?k=mini+zip+ties) |

## Wiring Option A – S2 Mini / Hand-Wired Harness

| Item | Qty | Notes | Amazon |
| --- | --- | --- | --- |
| Lolin/WeMos ESP32-S2 Mini | 1 | Native USB-C, fits on perfboard for the hand-wired build | [link](https://www.amazon.com/s?k=esp32+s2+mini) |
| Small protoboard (approx. 5×7 cm) | 1 | Hosts the header matrix and rails | [link](https://www.amazon.com/s?k=prototype+perfboard) |
| 3-pin male headers | 8 | Build the servo breakout; match spacing to MG90 plugs | [link](https://www.amazon.com/s?k=pin+header+strip) |
| Buck converter (5–12 V in to stable 5V/3A out) | 1 | Powers motors + MCU when using batteries | [link](https://www.amazon.com/s?k=3a+dc+dc+buck+converter+module) |

## Wiring Option B – Sesame Distro Board V2 (Included in Build Kits)

> [!NOTE]
> If you purchased a Sesame Build Kit, your V2 Distro Board is already assembled, pre-flashed, and included. You don't need to order these parts separately.

| Item | Qty | Notes | Amazon |
| --- | --- | --- | --- |
| Sesame Distro Board V2 PCB | 1 | Fully SMD design. Order with PCBway assembly service or attempt advanced hand soldering. See [ordering guide](/hardware/pcb/README.md) | [link](/hardware/pcb/README.md) |

## Wiring Option C – Sesame Distro Board V1 / ESP32-DevKitC-32E (Legacy)

> [!CAUTION]
> V1 is now phased out but still supported. Only choose this if you already have a V1 board.

| Item | Qty | Notes | Amazon |
| --- | --- | --- | --- |
| ESP32-DevKitC-32E (ESP32-WROOM-32) | 1 | Base board the Distro Board V1 stacks on. This one is very tricky because its a very specific board. You can use the 32E with the floating pcb antenna OR you can use the 32U but you have to route an antenna inside. | [link](https://www.amazon.com/s?k=ESP32+DevKitC+32) |
| Sesame Distro Board V1 PCB | 1 | Order `Gerber_Sesame-Distro-Board_PCB_Sesame-Distro-Board_V1.zip` via PCBway | [link](/hardware/pcb/README.md) |
| 5V buck converter (same spec as above) | 1 | Mounts on the distro board pads | [link](https://www.amazon.com/s?k=3a+dc+dc+buck+converter+module) |
| 4-pin JST-XH or PH header | 1 | Optional external connector footprint on PCB | [link](https://www.amazon.com/s?k=jst+xh+4+pin+kit) |
| 2-pin screw terminal (2.54 mm pitch) | 1 | Optional battery input on PCB | [link](https://www.amazon.com/s?k=2+pin+screw+terminal+block+2.54mm+pitch) |
| M2.5 × 5 mm male-female standoffs | 4 | Elevate the PCB over the DevKit mounting holes | [link](https://www.amazon.com/s?k=m2.5+male+female+standoff+5mm) |

## Power Sources & Connectors

| Item | Qty | Notes | Amazon |
| --- | --- | --- | --- |
| 3S 450 mAh LiPo with XT30 | 1 | Recommended wireless pack; ensure high-discharge rating | [link](https://www.amazon.com/s?k=3s+450mah+lipo+xt30) |
| 2× AAA holder | 1 set | 2S pack using AAA size Li-Ion Batteries (~7.4 V nominal) that fits the chassis battery slot; use a buck converter | [link](https://www.amazon.com/s?k=2x+aaa+battery+holder) |
| 10440 Li-ion cells (350–400 mAh typical) | 2 | Standard 10×44 mm Li-ion cells; buy spares | [link](https://www.amazon.com/s?k=10440+li-ion+cell+350mah) |
| 2-slot 10440 Li-ion charger | 1 | Charge cells outside the holder; avoid in-holder charging unless the holder is designed for it | [link](https://www.amazon.com/s?k=10440+li-ion+charger+2+slot) |
| XT30 female pigtail | 1 | Interface battery to switch/PCB without cutting stock leads | [link](https://www.amazon.com/s?k=xt30+female+pigtail) |

## Fasteners & Mechanical Hardware

| Item | Qty | Usage | Amazon |
| --- | --- | --- | --- |
| M2 × 5 mm self-threading screws | ~40 | All plastic joints, OLED retention, motor mounts, and covers (Can just get a variety pack) | [link](https://www.amazon.com/s?k=m2+self+tapping+screws+kit) |
| M2.5 × 5mm machine screws | 10 | Servo horn attachment to servo shafts only. Included servo horn screws are usually too short. | [link](https://www.amazon.com/s?k=m2+machine+screw+kit) |

## 3D Printed Parts

Print the 11-part part set outlined in [printing/README.md](../printing/README.md). STL and CAD sources live under `hardware/printing/`.

## Consumables & Tools Checklist

| Item | Notes | Amazon |
| --- | --- | --- |
| Leaded solder (0.6–0.8 mm) | Easier flow for dense perfboard work | [link](https://www.amazon.com/s?k=63%2F37+solder+0.8mm) |
| Flux pen | Protects pads on the perfboard and PCB | [link](https://www.amazon.com/s?k=flux+pen) |
| Solder wick / pump | For rework on the OLED pins | [link](https://www.amazon.com/s?k=solder+wick) |
| Small flush cutters | Trim servo leads, perfboard traces, or supports | [link](https://www.amazon.com/s?k=flush+cutters) |
| Precision screwdriver set | Needed for self-tapping M2 hardware | [link](https://www.amazon.com/s?k=precision+screwdriver+set) |

## Power & Safety Notes

- Sesame needs at least 5 V at 3 A available at the rails. 
- **Lolin S2 Mini:** Can be powered via USB-C PD (5V/3A capable) for tethered operation, or via battery + buck converter.
- **Distro Board V2:** Supports both USB-C PD (5V/3A) for tethered operation AND battery + buck converter. Included in all Sesame Build Kits.
- **Distro Board V1 (Legacy):** Cannot run on tethered USB-C power due to design limitations. Must use battery + buck converter for operation.
- When battery powering either build, route the pack through the rocker switch and buck converter before it touches the rails, mirroring the schematic in [docs/wiring-guide/README.md](../../docs/wiring-guide/README.md).
- **Never cut the factory battery connector off the pack.** Instead, create adapter pigtails using XT30 or JST RCY leads so the pack remains chargeable.
- A 2× 10440 Li-ion + 2× AAA holder pack fits the stock battery cavity and works well with the existing power switch + buck converter.
- **Always remove and charge 10440 cells separately in a proper Li-ion charger.** Do not charge them while inside the AAA holder unless the holder explicitly supports safe Li-ion charging (most do not).

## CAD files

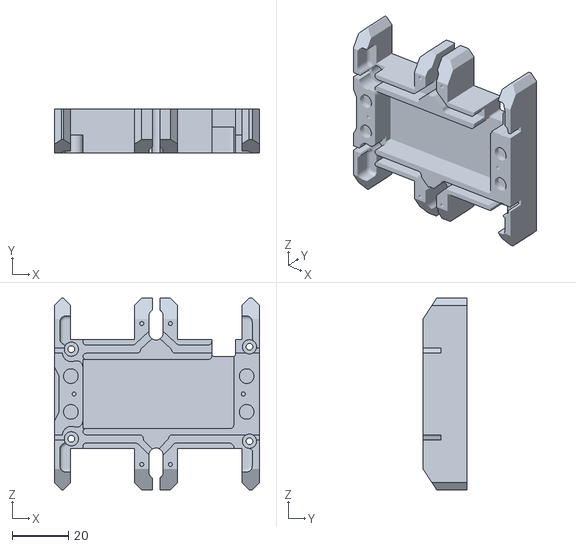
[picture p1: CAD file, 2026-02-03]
hardware/printing/stl/internal-frame-v90.stl
72.9 x 15.7 x 68.1

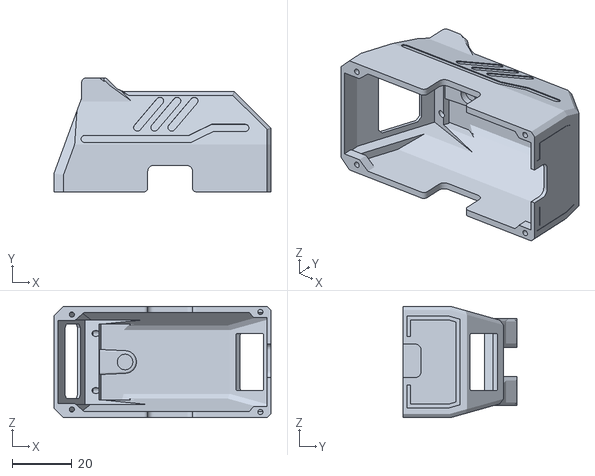
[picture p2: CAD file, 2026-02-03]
hardware/printing/stl/top-covers/sesame-top-cover-enclosed-v91.stl
72.9 x 38.2 x 37.4

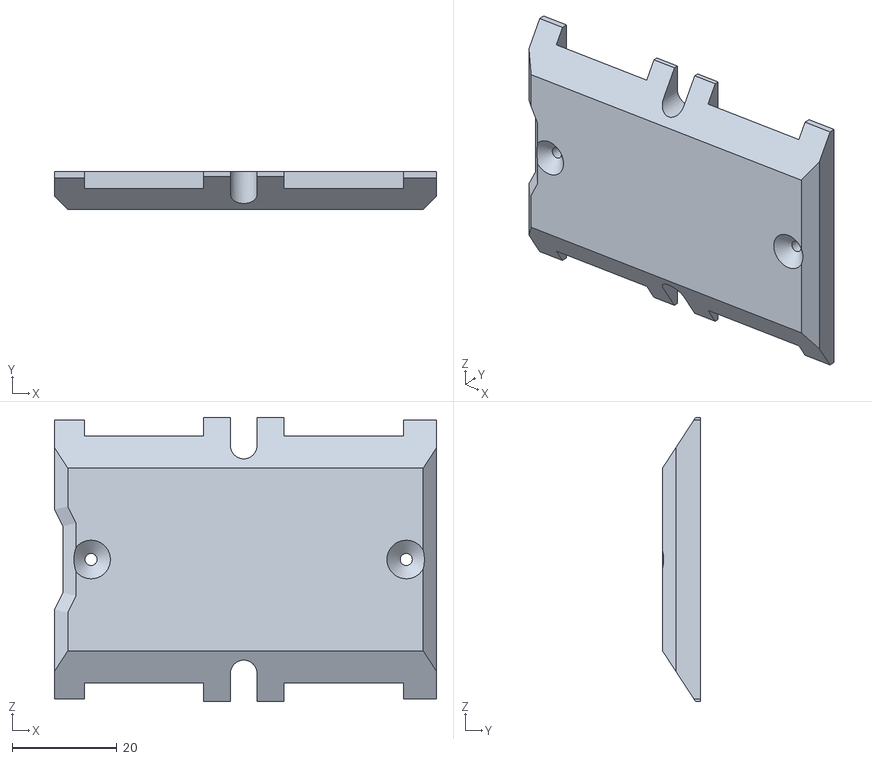
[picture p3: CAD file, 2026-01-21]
hardware/printing/stl/bottom-cover-v90.stl
72.9 x 7.27 x 54.2

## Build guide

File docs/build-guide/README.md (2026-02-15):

# Build Guide
Complete build guide for the Sesame Robot.

Use this walkthrough alongside the BOM, wiring guide, and printing notes to stay organized. The table below previews each phase, its goal, and the doc to reference if you get stuck.

| Phase | Goal | Est. Time | Key References |
| --- | --- | --- | --- |
| 1. Gather parts | Print plastics and source electronics | 1–2 sessions | [hardware/bom](../../hardware/bom/README.md), [hardware/printing](../../hardware/printing/README.md) |
| 2. Electronics & wiring | Build ~90% of the harness | 1 session | [docs/wiring-guide](../wiring-guide/README.md) |
| 3. Hardware pre-assembly | Prep joints, feet, top cover | 1 session | This guide (Phase 3) |
| 4. Hardware main assembly | Mount motors + electronics | 1–2 sessions | This guide (Phase 4) |
| 5. Calibrate & finish | Flash tester, align joints, close up | 1 session | Firmware README + remaining sections |

> [!TIP]
> Treat each phase like a milestone. Snap progress photos and mark issues before moving on so troubleshooting later is painless.

## Phase 1: Gathering all the parts.

**Goal:** Print the full shell set and collect every electronic, connector, and fastener before any soldering starts.

**You’ll need:**
- [hardware/bom](../../hardware/bom/README.md) for electronics, power gear, and Amazon search links.
- [hardware/printing](../../hardware/printing/README.md) for STL names, orientations, and support notes.

There are 11 printed parts (internal frame, top/bottom covers, joints R1–R4/L1–L4) plus 6–8 main electronic components depending on the wiring approach.

Here's what a complete set looks like:

all-hardware

**Phase 1 checklist**
- [ ] All plastic parts printed, and cleaned up.
- [ ] MG90 servos tested quickly on a servo tester or Arduino to catch DOA units.
- [ ] Power plan decided (USB-C PD vs. battery + buck) and matching connectors sourced (2× 10440 Li-ion cells in a 2× AAA holder fit the stock battery cavity).
- [ ] Consumables stocked: solder, flux, heat-shrink, zip ties, M2 hardware.

## Phase 2: Electronics and Wiring

**Goal:** Build 90% of the harness on the bench so the frame install is quick.

1. Open the [wiring guide](../wiring-guide/README.md) and pick the section that matches your build (S2 Mini hand-wired, Distro Board V2, or Distro Board V1 legacy).
2. Lay out every connector in the order shown on the wiring diagram before soldering; this keeps the data lines from getting crossed.
3. Tin and solder the rails/buck converter first, then route signal wires. Leave generous length for the motors that terminate near the hips.
4. This is optional but you can also label each servo lead (S0–S7) using tape flags as soon as it is soldered. Future you will thank you.

> [!WARNING]
> Stop before permanently wiring the power switch or OLED. Those final joints happen after the electronics are seated in the frame so you can dial the cable length exactly.

**Phase 2 checklist**
- [ ] Harness built per your wiring diagram with all joints strain-relieved.
- [ ] Buck converter trimmed to 5.1 V output and shrink-wrapped.
- [ ] Servo leads labeled and loosely bundled by destination.
- [ ] Power switch and OLED leads pre-cut but still un-soldered.

## Phase 3: Hardware Pre-Assembly

### Femur Joints

**Goal:** Pre-load the four femur shells (R1, R2, L1, L2) with servo horns so installation is tool-free later.

1. Lay out the four femur parts and make sure the embossed labels stay readable after sanding.
2. Press-fit a single-sided servo horn into each slot. Trim flash or lightly sand the slot if the horn binds.
3. While holding the horn flat, drive an M2 × 5 mm self-threading screw through the horn and into the plastic until snug.

install-horn

> [!TIP]
> Stop as soon as the horn no longer wiggles. Over-tightening will strip the plastic threads and loosen the fit.

Repeat for all four femur joints:

femur-joints

> [!IMPORTANT]
> Do **not** mount these joints on the servos yet. Calibration requires every motor shaft to spin freely.

dont-mount

### Foot Joints

Slide each foot shell over its dedicated motor before the frame install. Use the built-in gap to route wires without pinching them.



- Start by feeding the motor wires through the side slot.
- Push the shell until it momentarily flexes and snaps past the wire bundle.
- Confirm the motor sits flush and the wires exit straight out the back.

Repeat for the remaining feet so every motor already has its foot once calibration is done.



### Top Cover

The final pre-assembly step is loading the OLED and power switch into the top cover so the shell is ready for final wiring later. Since there are two main styles of top cover (Enclosed and Original) I will go over both.

#### Original Top Cover:

1. Slide the OLED display into the front slot until the bezel sits flush.

insert-display

2. If the fit is loose, drive two M2 × 5 mm self-threading screws through the angled bosses to clamp the PCB.

securing-display

#### Enclosed Top Cover:

1. Wire the data, power, and ground wires to the OLED display. 

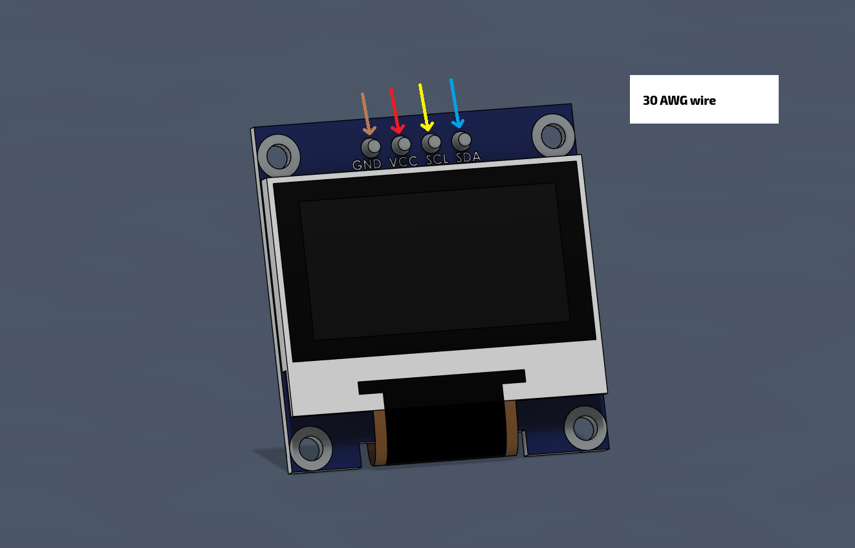
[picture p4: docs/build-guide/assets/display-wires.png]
display-wires


1. Push the OLED display into the front slot through the inside of the top cover.

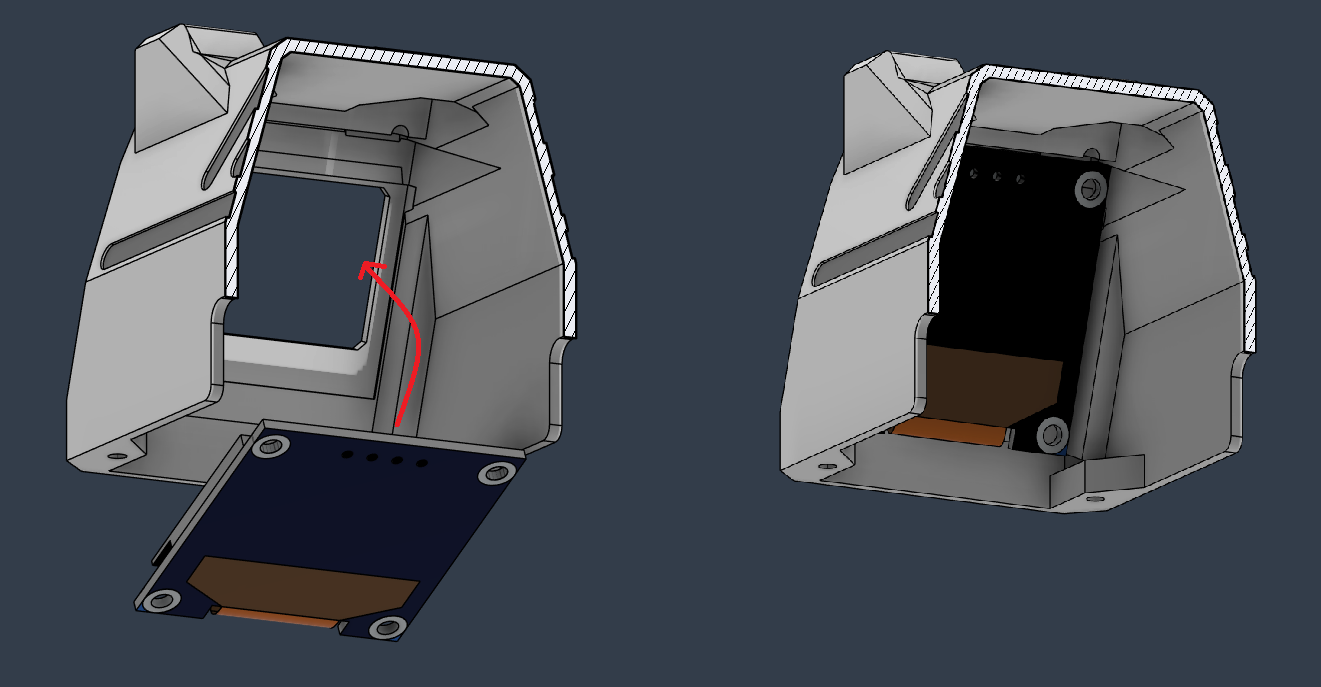
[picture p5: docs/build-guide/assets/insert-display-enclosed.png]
insert-display-enclosed


2. If the fit is loose, drive two M2 × 5 mm self-threading screws through the angled holes in the ears to clamp the PCB. You can also use a drop of removable hot glue to keep it in place.

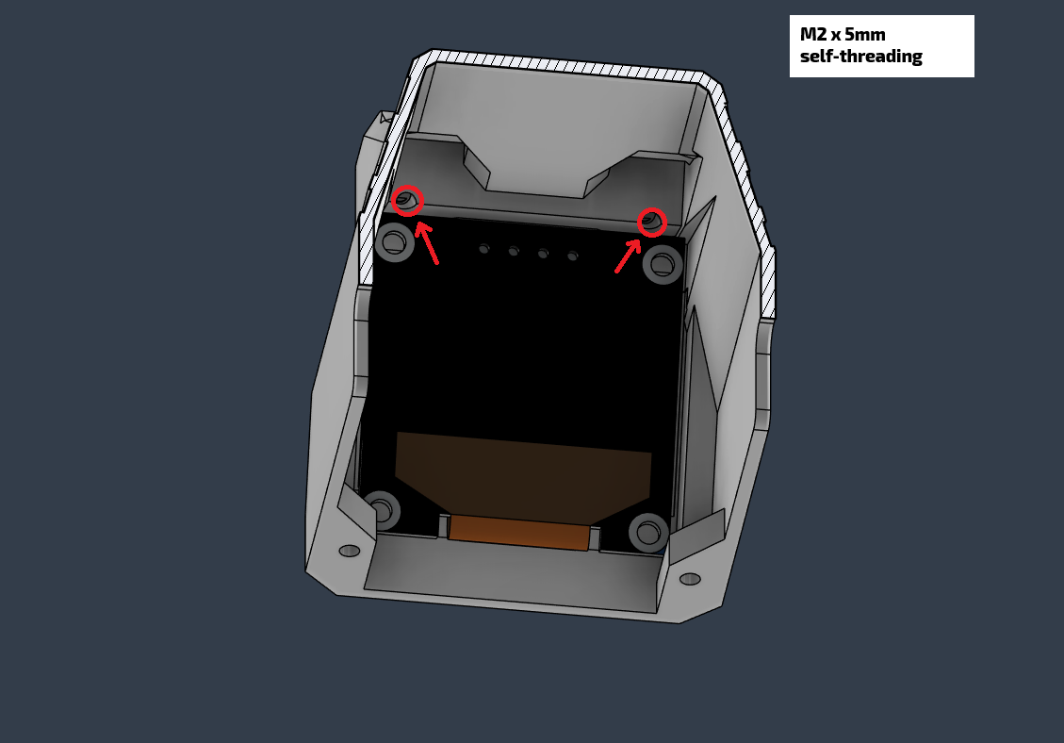
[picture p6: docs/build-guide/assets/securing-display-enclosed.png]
securing-display


#### Both:

3. Remove the factory pin header as it interferes with clearance. Either heat all four pins at once and pull, or clip them flush with snips.

remove-headers

4. Flip the cover and press-fit the rocker switch into the square cutout. Trim extra plastic on the switch housing if it refuses to seat. 

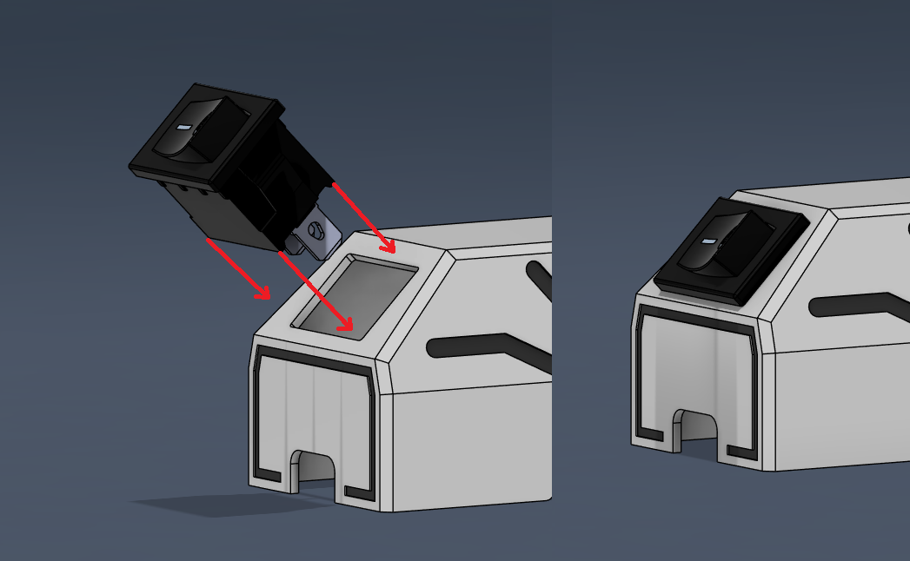
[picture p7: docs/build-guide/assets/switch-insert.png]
insert-rocker-switch


> [!NOTE]
> You can bend the rocker switch leads flat to make it fit better with the wires inside the top cover.

**Phase 3 checklist**
- [ ] Femur joints pre-loaded with servo horns, not yet attached to motors.
- [ ] Foot shells installed on every motor.
- [ ] OLED and rocker switch pressed into the top cover (wires untinned).

## Phase 4: Hardware Main Assembly

**Goal:** Seat the frame motors, route wiring, and secure the electronics stack so the robot is ready for calibration.

1. Dry-fit each MG90 (with foot attached) into its slot to make sure the wires naturally point toward the center.
2. Use the rotate-in technique: push the motor in horizontally, then pivot upright once the body clears the lip.

insert-motors

While pushing the motor in horizontally, take care to ensure the wires for the motor end up in their guide slot.

wire-spot

Once in, rotate the motor upwards, making sure the wires are not colliding with the internal frame. 

rotate-motor

Repeat for all four motors. Make sure the motor shafts are closest to the outer edge of the frame and mirror side-to-side. Secure each motor with M2 × 5 mm self-threading screws.

complete-motors

### Wire Routing

Route each motor lead through the recessed channels molded into the internal frame. A flat-head screwdriver or spudger helps press the wires fully into the grooves.

- Keep data lines tucked along the side walls so the electronics harness can drop into the middle later.
- Add a zip tie where the bundles exit the frame to prevent them from springing back out.
- Leave the bottom cover off for now so you can tug on individual wires during calibration if needed.

## Installing the Main Electronics

Before dropping hardware in, trim or bundle any stray wires so nothing can flop into the servo gears and double-check that every connection exits upward.

1. Pre-route any long wires upward so they naturally hug the future top cover.
2. Lower the electronics harness into the cavity while keeping the USB port toward the rear.
3. **S2 Mini build:** Screw the controller (and optional protoboard) directly into the frame using the provided mounting holes. If you built a small protoboard backplane, use the spare holes in the internal frame to secure it so the servo plugs are easy to reach later.

s2-secure-electronics

4. **Distro Board V1 build (Legacy):** Install four M2.5 × 5 mm male-female standoffs to raise the Sesame Distro Board V1 so it clears the ESP32 DevKit. Then secure the assembly using the top screws.
4. **Distro Board V2 build (Build Kits):** Mount according to V2 specifications (typically with standoffs provided in the kit).

s2-secure-distro-board

> [!TIP]
> Notch = front. USB port = back. Use these two cues any time the orientation feels ambiguous.

## Calibrating & Running the Testing Firmware

**Goal:** Teach the controller where each motor sits so the walking poses land correctly.

1. Inspect the harness to ensure no bare conductors can short during testing. Add heat-shrink or tape where needed, especially near the OLED and buck converter pads.
2. Connect a reliable USB-C cable and flash `sesame-motor-tester.ino` from the [debugging-firmware](../../firmware/debugging-firmware/) folder using Arduino IDE. If you have never flashed an ESP32 before, pause here and follow a quick tutorial so you are comfortable resetting/entering boot mode.
3. Open the serial monitor; you should see the tester menu. The robot should still look like a pile of parts. None of the motors should be plugged into horns or even into the board yet.

> [!CAUTION]
> Never run calibration with joints attached. A misaligned horn can stall or strip a servo instantly.

4. Command all motors to 90°. Starting from Motor 0, plug its connector into the appropriate header (topmost plug on a Distro Board). If you built the hand-wired perfboard, this will be whichever socket you designated as M0. Double-check the labeling you added earlier. The servo should immediately whirr into the 90° position.
5. Repeat for Motors 1–7, following the [angle guide](assets/sesame-angle-guide.png) (which shows the correct 90° reference position for each motor when viewed from the back) while viewing the robot from the back so left/right do not get flipped. Take your time; swapping two plugs is the #1 cause of calibration failures.

angle-guide

6. With all motors powered at 90°, press the femur joints onto their matching shafts (text emboss up) and mimic the reference stance.

reference-configuration

7. Run through each motor’s reference angles (center, min, max) from the serial CLI and confirm they move freely without collisions. Do **not** install the servo screws yet; you want the option to pop a horn off if a motor behaves strangely.

Common fixes (translated from the questions I get most often):

- **Setting Motor 0/1/2/3 to a maximum angle causes a crash.** Double-check that each motor’s data wire goes to the correct header. The hips sit close together and it’s easy to reverse two plugs when the harness is loose.
- **Setting Motor 4/5/6/7 straight down (0°/180°) makes the motor drive into the bottom cover.** Pull the horn off, command the opposite extreme (for Motors 4 & 6 use 180°, for 5 & 7 use 0°), then reinstall the horn pointing straight up. Run 90° again to recenter before retrying the straight-down move.
- **A motor refuses to move at all.** Confirm the servo is actually powered by gently touching it. An unpowered servo will feel loose. If loose, inspect the 3-pin plug for reversed polarity.

Finish by driving an M2.5 × 5 mm machine screw (the included servo horn screws are often too short) into each horn once every joint passes the min/center/max tests.

> [!TIP]
> After calibration is complete, the main firmware (`sesame-firmware-main.ino`) also includes individual motor control via the serial monitor, which is useful for testing and troubleshooting after assembly.

## Top Cover and Final Wiring

1. Rest the top cover on the hip joints, display facing forward. Make sure the robot is unpowered before touching the iron to anything.
2. Trim OLED and power-switch leads to length, then solder them while the cover is propped in place so you can fine-tune cable slack without stressing the pads.

top-cover-wiring

3. Spend a few minutes bundling the excess wire with zip ties or heat-shrink. Route everything toward the rear corners so the cover can close. “Jam it and hope” almost always ends with a pinched wire and a dead ESP32 (ask me how I know).

> [!TIP]
> If the cover refuses to seat, remove it and relocate the densest bundle rather than forcing it. Compressed wires can short against the pin headers.

4. Press the cover down until it sits flush with the internal frame.

push-on-top-cover

5. While holding the cover, insert four M2 × 5 mm self-threading screws from the underside and snug them just enough to hold the shell.

secure-top-cover

6. Drop the battery into the cavity (if using one) before closing the bottom panel. A 2× AAA holder with 10440 Li-ion cells fits the stock slot cleanly; remove the cells to recharge. Unique battery shapes can be accommodated. See [hardware/README.md](../../hardware/README.md) for CAD tips. Tethered-only builds can skip the pack.

## Bottom Cover

insert-battery

1. Tuck any remaining outer-motor leads through the front/back slots so they lie flat.
2. Set the bottom cover in place, checking that no wires are trapped along the edges.

push-on-bottom-cover

3. Secure the plate with two M2 × 5 mm self-threading screws.

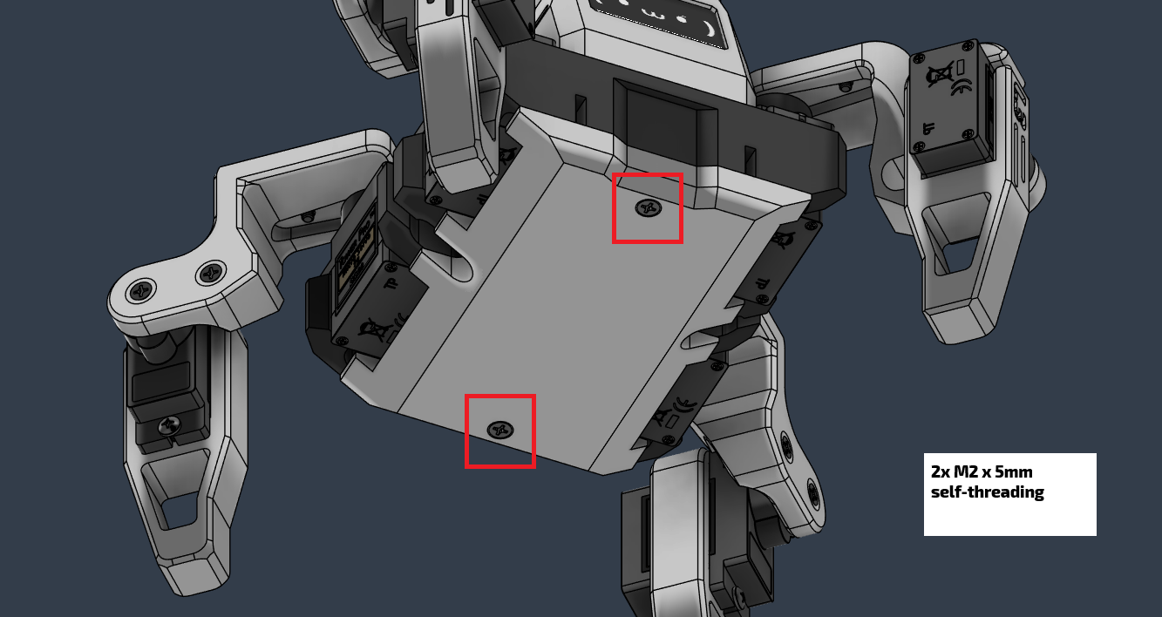
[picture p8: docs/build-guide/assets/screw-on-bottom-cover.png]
screw-on-bottom-cover


**Phase 4 checklist**
- [ ] Motors mounted and screws snug.
- [ ] Harness routed with no pinch points; electronics stack secured.
- [ ] Top and bottom covers installed, but easy to remove again if calibration needs a revisit.

## Final Checks and Flashing the Firmware

Great job! The hardware is complete, now we just need to do a few checks to make sure everything is working and we can flash the firmware onto the microcontroller.

sesame-done

**Sanity checks**
1. Toggle the power switch (if you installed a battery) and confirm it fully disconnects the pack.
2. Confirm the USB-C port is accessible for future firmware updates.
3. Inspect the OLED wiring one last time to ensure SDA/SCL aren’t swapped.

**Flash production firmware**
1. Choose the code variant (S2 Mini, Distro Board V2, or Distro Board V1 legacy) from the firmware folder. Customize pin definitions if you're using a different ESP32.
2. Use Arduino IDE to flash the full firmware bundle (motors + faces). Detailed notes live in [firmware/README.md](../../firmware/README.md).
3. Connect to Sesame’s Wi-Fi AP, load the control page, and trigger a pose to verify everything moves as expected.

That’s it. You’ve built Sesame! From here you can design new poses in [Sesame Studio](../../software/sesame-studio/README.md) or tweak the hardware per [hardware/README.md](../../hardware/README.md), or whatever you want!

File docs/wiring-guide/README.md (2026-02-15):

# Wiring Guide

Complete wiring guides for the Sesame Robot.

---

## Choosing a Wiring Approach

The project supports multiple wiring strategies that suit different build constraints:

- **Lolin S2 Mini / hand wiring (RECOMMENDED FOR DIY BUILDS):** Uses a Lolin S2 Mini, loose headers, and point-to-point wiring. It is the lowest-cost option, easy to source, supports USB-C PD for tethered power, but demands patience to keep the harness tidy and leaves less room for mistakes. **Critical: Use 30AWG wire for data lines and 22AWG for power—larger gauge wire will make assembly nearly impossible.**
- **Sesame Distro Board V2 (INCLUDED IN BUILD KITS):** The latest custom PCB with SMD components, supports both USB-C PD and battery power. Pre-flashed and included with all Sesame Build Kits. Advanced to hand-solder; professional assembly recommended if ordering separately.
- **Sesame Distro Board V1 / ESP32-DevKitC-32E (LEGACY):** Uses the custom Distro Board V1 PCB stacked on an ESP32-DevKitC-32E. Now phased out but still supported. V1 has known limitations and cannot run on tethered USB-C power (battery + buck converter required).

Pick the approach that matches your component availability and comfort with managing wire bundles; the remainder of this guide dives into both workflows.

## How to wire the Lolin S2 Mini / Hand Wiring

The Lolin S2 Mini method is a traditional protoboard build. Consult the S2 Mini wiring diagram below while reading this section; it captures every motor, sensor, OLED, and button lead even if the photos only show a subset of the connections. Expect a high connection count, so plan wire lengths and colors before soldering to avoid confusion later.

S2 Mini wiring diagram

### Prep

1. **Secure and tin** all of the connections on the board before starting
2. To connect all the 3-pin headers together and to the board, first attach them to a small section of protoboard

proto-headers

### Building Power and Ground Rails

1. Solder one wire to one end of the pins, then guide it along and remove the insulation
2. Solder this exposed wire to every middle pin (this creates the **5V rail**)
3. Do the same for the ground lane (this creates the **ground rail**)

proto-power-rails

### Data Lines

You can now cut eight equal-length wires for data connections.

**Wire Recommendations:**
- **Data lines:** 30AWG silicone wire
- **Power and ground:** 22AWG silicone wire
- **Important:** Things will get super cluttered if you use large gauge wire

proto-data-lines

Alongside the eight motor data leads, the diagram also calls out the OLED connections that branch from the microcontroller.

### Packing Electronics

When packing electronics into the frame, it's difficult with the hand wiring setup because there are a lot of stray wires. My advice is to work slowly and methodically:

1. Group wires with similar destinations
2. Use zip ties and heat shrink tubing to make them as compact as possible
3. Consider connecting the power switch after finishing most other wiring, since it's attached to the top cover

wire-managment

### Safety and Testing

> [!CAUTION]
> Do not solder and de-solder connections with power connected!

**Before powering on:**
- Double check your power and ground lines before turning the robot on
- Make sure to cover any exposed wires as they can touch the pin headers and fry the ESP32 (especially when cramming the cover on)

> [!TIP]
> To make fishing out the wires for the OLED display easier, you can temporarily twist them together into a group and then guide them through the opening in the top cover.

---

## How to wire the Sesame Distro Board V1 / ESP32-DevKitC-32E

### Overview

> [!CAUTION]  
> UPDATE 1/20/26: Upon further testing, the Sesame distro board V1 will work, but it has a few issues that make it a little harder to assemble and will not run on teathered power (eg. USB C). Until V2 is released, I recommend using the S2 Mini / Hand Wiring approach. If you ordered a distro board V1, it will still be supported with wiring guides and firmware for the foreseeable future <3.

This option provides a cleaner, more organized wiring solution.
Consult the distro-board wiring diagram below for exact connection locations.

> [!IMPORTANT]
> **ESP32 Pin Header Requirement:** The distro board V1 stacks on top of the ESP32-DevKitC-32E, so you need an ESP32 board **without pre-soldered pin headers**. If your board came with headers already soldered on the top, you will need to desolder all of the headers and flip them to the bottom side of the ESP32 board so the distro board can mount on top.

distro-board wiring diagram

### Component Installation

**Optional components** (you can solder directly to pads instead):
- 4-pin JST connector
- 2-pin screw terminal

**Pin header installation tip:** If you're having difficulties keeping the pin headers in place to solder, try placing them in a protoboard first, then transferring them over.

### Buck Converter Setup

A buck converter takes any voltage (5V-12V) and drops it to a stable 5V for the motors and ESP32.

**If using a battery:**
1. Make sure to solder the buck converter enable pads
2. The buck converter is **required** for battery operation
3. 2× 10440 Li-ion cells in a 2× AAA holder (2S, ~7.4 V nominal) work well with the buck and fit the chassis battery slot

**Alternative power options:**
- If you're using a benchtop supply or have another regulated 5V source
- You can override the buck converter and take voltage directly from the screw terminal by soldering the override pads

### Battery Connection
> [!CAUTION]
> If your battery has an XT30 or JST RCY connector, don't cut it off and wire the battery directly to the distro board! This is unsafe and means you can't charge your battery anymore.

**Proper method:**
1. Get a female XT30 or JST RCY connector (matching your battery)
2. Wire it to two wires that lead to the power terminal
3. This allows you to safely connect and disconnect the battery

**Note on 2× AAA holders with 10440 Li-ion cells:**
- Treat this as a 2S Li-ion pack; wire the holder leads through the switch and buck converter.
- **Always remove the 10440 cells from the holder and recharge them separately using a proper Li-ion charger.** Most AAA holders do not support safe Li-ion charging and attempting to charge in-holder can be dangerous.

### Sourcing the Distro Board

The Sesame Distro Board V1 is a custom PCB designed specifically for this project. It mounts on top of a ESP32-DevKitC-32E.

More information is avalible in the [PCB](../../hardware/pcb/README.md) section of the documentation.

---

## General Wiring Tips

- Work slowly and methodically
- Test connections before applying power
- Keep wire runs as short and neat as possible
- Label wires if helpful for troubleshooting
- Take photos during assembly for reference

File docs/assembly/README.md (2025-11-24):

# Assembly Instructions

Step-by-step assembly instructions for building the Sesame Robot.

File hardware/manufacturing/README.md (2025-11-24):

# Manufacturing Files

Manufacturing and fabrication files including print profiles and Gerber files.

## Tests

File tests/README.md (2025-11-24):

# Tests

Test code and validation procedures for the Sesame Robot.

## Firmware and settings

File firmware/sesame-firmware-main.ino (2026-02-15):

#include <WiFi.h>
#include <WebServer.h>
#include <DNSServer.h>
#include <ESPmDNS.h>
#include <Wire.h>
#include <ESP32Servo.h>
#include <Adafruit_GFX.h>
#include <Adafruit_SSD1306.h>
#include "face-bitmaps.h"
#include "movement-sequences.h"
#include "captive-portal.h"

// --- Access Point Configuration ---
// This is the network the Robot will create
#define AP_SSID  "Sesame-Controller-BETA"
#define AP_PASS  "12345678" // Must be at least 8 characters

// --- Station Mode Configuration (Optional) ---
// Set these to connect to your home/office WiFi network
// Leave NETWORK_SSID empty to disable station mode
#define NETWORK_SSID ""  // Your WiFi network name
#define NETWORK_PASS ""  // Your WiFi password
#define ENABLE_NETWORK_MODE false  // Set to true to enable network connection attempts

#define SCREEN_WIDTH 128
#define SCREEN_HEIGHT 64
#define OLED_RESET -1
#define OLED_I2C_ADDR 0x3C

// I2C Pins for Distro Board V2
//#define I2C_SDA 8
//#define I2C_SCL 9

// I2C Pins for Distro Board
//#define I2C_SDA 21
//#define I2C_SCL 22

// I2C Pins for S2 Mini Board
#define I2C_SDA 33
#define I2C_SCL 35


// DNS Server for Captive Portal
DNSServer dnsServer;
const byte DNS_PORT = 53;

Adafruit_SSD1306 display(SCREEN_WIDTH, SCREEN_HEIGHT, &Wire, OLED_RESET);
WebServer server(80);

// Global state for animations
String currentCommand = "";
String currentFaceName = "default";
const unsigned char* const* currentFaceFrames = nullptr;
uint8_t currentFaceFrameCount = 0;
uint8_t currentFaceFrameIndex = 0;
unsigned long lastFaceFrameMs = 0;
int faceFps = 8;
FaceAnimMode currentFaceMode = FACE_ANIM_LOOP;
int8_t faceFrameDirection = 1;
bool faceAnimFinished = false;
int currentFaceFps = 0;
bool idleActive = false;
bool idleBlinkActive = false;
unsigned long nextIdleBlinkMs = 0;
uint8_t idleBlinkRepeatsLeft = 0;

// WiFi Info Scrolling
unsigned long lastInputTime = 0;
bool firstInputReceived = false;
bool showingWifiInfo = false;
int wifiScrollPos = 0;
unsigned long lastWifiScrollMs = 0;
String wifiInfoText = "";

// Network Mode
bool networkConnected = false;
IPAddress networkIP;
String deviceHostname = "sesame-robot";

// Servo Pins for Distro Board
// ======================================================================
// Pin numbers are coorisponding to the ESP32 GPIO pins and may differ based on which board you use.
// If you are using a different board, please adjust the servoPins array accordingly.
// ======================================================================
Servo servos[8];
// Sesame Distro Board V2 Pinout
//const int servoPins[8] = {4, 5, 6, 7, 15, 16, 17, 18};

// Sesame Distro Board Pinout
//const int servoPins[8] = {15, 2, 23, 19, 4, 16, 17, 18};

// Lolin S2 Mini Pinout
const int servoPins[8] = {1, 2, 4, 6, 8, 10, 13, 14};

// Subtrim values for each servo (offset in degrees)
int8_t servoSubtrim[8] = {0, 0, 0, 0, 0, 0, 0, 0};


// Animation constants
int frameDelay = 100;
int walkCycles = 10;
int motorCurrentDelay = 20; // ms delay between motor movements to prevent over-current

struct FaceEntry {
  const char* name;
  const unsigned char* const* frames;
  uint8_t maxFrames;
};

static const uint8_t MAX_FACE_FRAMES = 6;

#define MAKE_FACE_FRAMES(name) \
  const unsigned char* const face_##name##_frames[] = { \
    epd_bitmap_##name, epd_bitmap_##name##_1, epd_bitmap_##name##_2, \
    epd_bitmap_##name##_3, epd_bitmap_##name##_4, epd_bitmap_##name##_5 \
  };

#define X(name) MAKE_FACE_FRAMES(name)
FACE_LIST
#undef X
#undef MAKE_FACE_FRAMES

const FaceEntry faceEntries[] = {
#define X(name) { #name, face_##name##_frames, MAX_FACE_FRAMES },
  FACE_LIST
#undef X
  { "default", face_defualt_frames, MAX_FACE_FRAMES }
};

struct FaceFpsEntry {
  const char* name;
  uint8_t fps;
};

const FaceFpsEntry faceFpsEntries[] = {
  { "walk", 1 },
  { "rest", 1 },
  { "swim", 1 },
  { "dance", 1 },
  { "wave", 1 },
  { "point", 5 },
  { "stand", 1 },
  { "cute", 1 },
  { "pushup", 1 },
  { "freaky", 1 },
  { "bow", 1 },
  { "worm", 1 },
  { "shake", 1 },
  { "shrug", 1 },
  { "dead", 2 },
  { "crab", 1 },
  { "idle", 1 },
  { "idle_blink", 7 },
  { "default", 1 },
  // Conversational faces (manually controlled by Python - no auto-animation)
  { "happy", 1 },
  { "talk_happy", 1 },
  { "sad", 1 },
  { "talk_sad", 1 },
  { "angry", 1 },
  { "talk_angry", 1 },
  { "surprised", 1 },
  { "talk_surprised", 1 },
  { "sleepy", 1 },
  { "talk_sleepy", 1 },
  { "love", 1 },
  { "talk_love", 1 },
  { "excited", 1 },
  { "talk_excited", 1 },
  { "confused", 1 },
  { "talk_confused", 1 },
  { "thinking", 1 },
  { "talk_thinking", 1 },
};


// Prototypes
void setServoAngle(uint8_t channel, int angle);
void updateFaceBitmap(const unsigned char* bitmap);
void setFace(const String& faceName);
void setFaceMode(FaceAnimMode mode);
void setFaceWithMode(const String& faceName, FaceAnimMode mode);
void updateAnimatedFace();
void delayWithFace(unsigned long ms);
void enterIdle();
void exitIdle();
void updateIdleBlink();
int getFaceFpsForName(const String& faceName);
bool pressingCheck(String cmd, int ms);
void handleGetSettings();
void handleSetSettings();
void handleGetStatus();
void handleApiCommand();
void updateWifiInfoScroll();
void recordInput();

void handleRoot() {
  server.send(200, "text/html", index_html);
}

void handleCommandWeb() {
  // We send 200 OK immediately so the web browser doesn't hang waiting for animation to finish
  if (server.hasArg("pose")) {
    currentCommand = server.arg("pose");
    recordInput();
    exitIdle();
    server.send(200, "text/plain", "OK"); 
  } 
  else if (server.hasArg("go")) {
    currentCommand = server.arg("go");
    recordInput();
    exitIdle();
    server.send(200, "text/plain", "OK");
  } 
  else if (server.hasArg("stop")) {
    currentCommand = "";
    recordInput();
    server.send(200, "text/plain", "OK");
  }
  else if (server.hasArg("motor") && server.hasArg("value")) {
    int motorNum = server.arg("motor").toInt();
    int servoIdx = servoNameToIndex(server.arg("motor"));
    int angle = server.arg("value").toInt();
    if (motorNum >= 1 && motorNum <= 8 && angle >= 0 && angle <= 180) {
      setServoAngle(motorNum - 1, angle); // Convert 1-based to 0-based index
      recordInput();
      server.send(200, "text/plain", "OK");
    } else if (servoIdx != -1 && angle >= 0 && angle <= 180) {
      setServoAngle(servoIdx, angle);
      recordInput();
      server.send(200, "text/plain", "OK");
    } else {
      server.send(400, "text/plain", "Invalid motor or angle");
    }
  }
  else {
    server.send(400, "text/plain", "Bad Args");
  }
}

void handleGetSettings() {
  String json = "{";
  json += "\"frameDelay\":" + String(frameDelay) + ",";
  json += "\"walkCycles\":" + String(walkCycles) + ",";
  json += "\"motorCurrentDelay\":" + String(motorCurrentDelay) + ",";
  json += "\"faceFps\":" + String(faceFps);
  json += "}";
  server.send(200, "application/json", json);
}

void handleSetSettings() {
  if (server.hasArg("frameDelay")) frameDelay = server.arg("frameDelay").toInt();
  if (server.hasArg("walkCycles")) walkCycles = server.arg("walkCycles").toInt();
  if (server.hasArg("motorCurrentDelay")) motorCurrentDelay = server.arg("motorCurrentDelay").toInt();
  if (server.hasArg("faceFps")) faceFps = (int)max(1L, server.arg("faceFps").toInt());
  server.send(200, "text/plain", "OK");
}

// API endpoint for network clients to get robot status
void handleGetStatus() {
  String json = "{";
  json += "\"currentCommand\":\"" + currentCommand + "\",";
  json += "\"currentFace\":\"" + currentFaceName + "\",";
  json += "\"networkConnected\":" + String(networkConnected ? "true" : "false") + ",";
  json += "\"apIP\":\"" + WiFi.softAPIP().toString() + "\"";
  if (networkConnected) {
    json += ",\"networkIP\":\"" + networkIP.toString() + "\"";
  }
  json += "}";
  server.send(200, "application/json", json);
}

// API endpoint for network clients to send commands (JSON-based)
void handleApiCommand() {
  if (server.method() != HTTP_POST) {
    server.send(405, "application/json", "{\"error\":\"Method not allowed\"}");
    return;
  }
  
  String body = server.arg("plain");
  
  Serial.println("API Command received:");
  Serial.println(body);
  
  // Check for face-only command (no movement)
  int faceOnlyStart = body.indexOf("\"face\":\"");
  if (faceOnlyStart == -1) {
    faceOnlyStart = body.indexOf("\"face\": \"");
  }
  
  // If we have a face but no command field, it's face-only
  bool faceOnly = (faceOnlyStart > 0 && body.indexOf("\"command\":") == -1 && body.indexOf("\"command\": ") == -1);
  
  String command = "";
  String face = "";
  
  // Parse face
  if (faceOnlyStart > 0) {
    faceOnlyStart = body.indexOf("\"", faceOnlyStart + 6) + 1;
    int faceEnd = body.indexOf("\"", faceOnlyStart);
    if (faceEnd > faceOnlyStart) {
      face = body.substring(faceOnlyStart, faceEnd);
      Serial.print("Parsed face: ");
      Serial.println(face);
    }
  }
  
  // Parse command (if not face-only)
  if (!faceOnly) {
    int cmdStart = body.indexOf("\"command\":\"");
    if (cmdStart == -1) {
      cmdStart = body.indexOf("\"command\": \"");
    }
    
    if (cmdStart == -1) {
      Serial.println("Error: command field not found");
      server.send(400, "application/json", "{\"error\":\"Missing command field\"}");
      return;
    }
    
    cmdStart = body.indexOf("\"", cmdStart + 10) + 1;
    int cmdEnd = body.indexOf("\"", cmdStart);
    
    if (cmdEnd <= cmdStart) {
      Serial.println("Error: invalid command format");
      server.send(400, "application/json", "{\"error\":\"Invalid command format\"}");
      return;
    }
    
    command = body.substring(cmdStart, cmdEnd);
    Serial.print("Parsed command: ");
    Serial.println(command);
  }
  
  // Set face if provided
  if (face.length() > 0) {
    setFace(face);
  }
  
  // If face-only, just acknowledge
  if (faceOnly) {
    recordInput();
    server.send(200, "application/json", "{\"status\":\"ok\",\"message\":\"Face updated\"}");
    return;
  }
  
  // Execute command
  if (command == "stop") {
    currentCommand = "";
    recordInput();
    server.send(200, "application/json", "{\"status\":\"ok\",\"message\":\"Command stopped\"}");
  } else {
    currentCommand = command;
    recordInput();
    exitIdle();
    server.send(200, "application/json", "{\"status\":\"ok\",\"message\":\"Command executed\"}");
  }
}

void setup() {
  Serial.begin(115200);
  randomSeed(micros());
  
  // I2C Init for ESP32
  Wire.begin(I2C_SDA, I2C_SCL);

  // OLED Init
  if (!display.begin(SSD1306_SWITCHCAPVCC, OLED_I2C_ADDR)) {
    Serial.println(F("SSD1306 allocation failed."));
    while (1);
  }
  
  display.clearDisplay();
  display.setTextColor(SSD1306_WHITE);
  display.setTextSize(1);
  display.setCursor(0,0);
  display.println(F("Setting up WiFi..."));
  display.display();

  // --- WIFI CONFIGURATION ---
  // Try to connect to network first if configured
  if (ENABLE_NETWORK_MODE && String(NETWORK_SSID).length() > 0) {
    Serial.println("Attempting to connect to network: " + String(NETWORK_SSID));
    WiFi.mode(WIFI_AP_STA); // Enable both AP and Station modes
    WiFi.setHostname(deviceHostname.c_str());
    WiFi.begin(NETWORK_SSID, NETWORK_PASS);
    
    // Wait up to 10 seconds for connection
    int attempts = 0;
    while (WiFi.status() != WL_CONNECTED && attempts < 20) {
      delay(500);
      Serial.print(".");
      attempts++;
    }
    
    if (WiFi.status() == WL_CONNECTED) {
      networkConnected = true;
      networkIP = WiFi.localIP();
      Serial.println();
      Serial.print("Connected to network! IP: ");
      Serial.println(networkIP);
    } else {
      Serial.println();
      Serial.println("Failed to connect to network. Running in AP-only mode.");
      WiFi.mode(WIFI_AP); // Fall back to AP-only
    }
  } else {
    WiFi.mode(WIFI_AP);
    Serial.println("Network mode disabled. Running in AP-only mode.");
  }
  
  // --- ACCESS POINT CONFIGURATION ---
  WiFi.softAP(AP_SSID, AP_PASS);
  IPAddress myIP = WiFi.softAPIP();
  
  Serial.print("AP Created. IP: ");
  Serial.println(myIP);

  // Build WiFi info text for scrolling
  if (networkConnected) {
    wifiInfoText = "AP: " + String(AP_SSID) + " (" + myIP.toString() + ")  |  Network: " + String(NETWORK_SSID) + " (" + networkIP.toString() + ") or " + deviceHostname + ".local  |  ";
  } else {
    wifiInfoText = "Connect to WiFi: " + String(AP_SSID) + "  |  Pass: " + String(AP_PASS) + "  |  IP: " + myIP.toString() + "  |  Captive Portal will auto-open!  |  ";
  }
  
  // Initialize input tracking
  lastInputTime = millis();
  firstInputReceived = false;
  showingWifiInfo = false;

  // Start mDNS responder for local network discovery
  if (MDNS.begin(deviceHostname.c_str())) {
    Serial.println("mDNS responder started");
    Serial.print("Access controller at: http://");
    Serial.print(deviceHostname);
    Serial.println(".local");
    MDNS.addService("http", "tcp", 80);
  } else {
    Serial.println("Error setting up mDNS responder!");
  }

  // Start DNS Server for Captive Portal
  // This redirects ALL domain requests to the ESP32's IP
  dnsServer.start(DNS_PORT, "*", myIP);

  // Web Server Routes
  server.on("/", handleRoot);
  server.on("/cmd", handleCommandWeb);
  server.on("/getSettings", handleGetSettings);
  server.on("/setSettings", handleSetSettings);
  
  // API endpoints for network communication
  server.on("/api/status", handleGetStatus);
  server.on("/api/command", handleApiCommand);
  
  // Catch-all route for captive portal
  // This ensures any URL redirects to the controller page
  server.onNotFound(handleRoot);
  
  server.begin();

  // PWM Init
  ESP32PWM::allocateTimer(0);
  ESP32PWM::allocateTimer(1);
  ESP32PWM::allocateTimer(2);
  ESP32PWM::allocateTimer(3);
  
  for (int i = 0; i < 8; i++) {
    servos[i].setPeriodHertz(50);
    // Map 0-180 to approx 732-2929us
    servos[i].attach(servoPins[i], 732, 2929);
  }
  delay(10);
  
  // Show rest face on startup without moving motors
  setFace("rest");
  
  Serial.println(F("HTTP server & Captive Portal started."));
}

void loop() {
  // Process DNS requests for captive portal
  dnsServer.processNextRequest();
  
  server.handleClient();
  updateAnimatedFace();
  updateIdleBlink();
  updateWifiInfoScroll();

  if (currentCommand != "") {
    String cmd = currentCommand;
    if (cmd == "forward") runWalkPose();
    else if (cmd == "backward") runWalkBackward();
    else if (cmd == "left") runTurnLeft();
    else if (cmd == "right") runTurnRight();
    else if (cmd == "rest") { runRestPose(); if (currentCommand == "rest") currentCommand = ""; }
    else if (cmd == "stand") { runStandPose(1); if (currentCommand == "stand") currentCommand = ""; }
    else if (cmd == "wave") runWavePose();
    else if (cmd == "dance") runDancePose();
    else if (cmd == "swim") runSwimPose();
    else if (cmd == "point") runPointPose();
    else if (cmd == "pushup") runPushupPose();
    else if (cmd == "bow") runBowPose();
    else if (cmd == "cute") runCutePose();
    else if (cmd == "freaky") runFreakyPose();
    else if (cmd == "worm") runWormPose();
    else if (cmd == "shake") runShakePose();
    else if (cmd == "shrug") runShrugPose();
    else if (cmd == "dead") runDeadPose();
    else if (cmd == "crab") runCrabPose();
  }
  
  // Serial CLI for debugging (can be used to diagnose servo position issues and wiring)
  if (Serial.available()) {
    static char command_buffer[32];
    static byte buffer_pos = 0;
    char c = Serial.read();
    if (c == '\n' || c == '\r') {
      if (buffer_pos > 0) {
        command_buffer[buffer_pos] = '\0';
        int motorNum, angle;
        recordInput();
        if(strcmp(command_buffer, "run walk") == 0 || strcmp(command_buffer, "rn wf") == 0) { currentCommand = "forward"; runWalkPose(); currentCommand = ""; }
        else if(strcmp(command_buffer, "rn wb") == 0) { currentCommand = "backward"; runWalkBackward(); currentCommand = ""; }
        else if(strcmp(command_buffer, "rn tl") == 0) { currentCommand = "left"; runTurnLeft(); currentCommand = ""; }
        else if(strcmp(command_buffer, "rn tr") == 0) { currentCommand = "right"; runTurnRight(); currentCommand = ""; }
        else if(strcmp(command_buffer, "run rest") == 0 || strcmp(command_buffer, "rn rs") == 0) runRestPose();
        else if(strcmp(command_buffer, "run stand") == 0 || strcmp(command_buffer, "rn st") == 0) runStandPose(1);
        else if(strcmp(command_buffer, "rn wv") == 0) { currentCommand = "wave"; runWavePose(); }
        else if(strcmp(command_buffer, "rn dn") == 0) { currentCommand = "dance"; runDancePose(); }
        else if(strcmp(command_buffer, "rn sw") == 0) { currentCommand = "swim"; runSwimPose(); }
        else if(strcmp(command_buffer, "rn pt") == 0) { currentCommand = "point"; runPointPose(); }
        else if(strcmp(command_buffer, "rn pu") == 0) { currentCommand = "pushup"; runPushupPose(); }
        else if(strcmp(command_buffer, "rn bw") == 0) { currentCommand = "bow"; runBowPose(); }
        else if(strcmp(command_buffer, "rn ct") == 0) { currentCommand = "cute"; runCutePose(); }
        else if(strcmp(command_buffer, "rn fk") == 0) { currentCommand = "freaky"; runFreakyPose(); }
        else if(strcmp(command_buffer, "rn wm") == 0) { currentCommand = "worm"; runWormPose(); }
        else if(strcmp(command_buffer, "rn sk") == 0) { currentCommand = "shake"; runShakePose(); }
        else if(strcmp(command_buffer, "rn sg") == 0) { currentCommand = "shrug"; runShrugPose(); }
        else if(strcmp(command_buffer, "rn dd") == 0) { currentCommand = "dead"; runDeadPose(); }
        else if(strcmp(command_buffer, "rn cb") == 0) { currentCommand = "crab"; runCrabPose(); }
        else if (strcmp(command_buffer, "subtrim") == 0 || strcmp(command_buffer, "st") == 0) {
          Serial.println("Subtrim values:");
          for (int i = 0; i < 8; i++) {
            Serial.print("Motor "); Serial.print(i); Serial.print(": ");
            if (servoSubtrim[i] >= 0) Serial.print("+");
            Serial.println(servoSubtrim[i]);
          }
        }
        else if (strcmp(command_buffer, "subtrim save") == 0 || strcmp(command_buffer, "st save") == 0) {
          Serial.println("Copy and paste this into your code:");
          Serial.print("int8_t servoSubtrim[8] = {");
          for (int i = 0; i < 8; i++) {
            Serial.print(servoSubtrim[i]);
            if (i < 7) Serial.print(", ");
          }
          Serial.println("};");
        }
        else if (strncmp(command_buffer, "subtrim reset", 13) == 0 || strncmp(command_buffer, "st reset", 8) == 0) {
          for (int i = 0; i < 8; i++) servoSubtrim[i] = 0;
          Serial.println("All subtrim values reset to 0");
        }
        else if (strncmp(command_buffer, "subtrim ", 8) == 0 || strncmp(command_buffer, "st ", 3) == 0) {
          const char* params = (command_buffer[1] == 't') ? command_buffer + 3 : command_buffer + 8;
          int trimMotor, trimValue;
          if (sscanf(params, "%d %d", &trimMotor, &trimValue) == 2) {
            if (trimMotor >= 0 && trimMotor < 8) {
              if (trimValue >= -90 && trimValue <= 90) {
                servoSubtrim[trimMotor] = trimValue;
                Serial.print("Motor "); Serial.print(trimMotor); Serial.print(" subtrim set to ");
                if (trimValue >= 0) Serial.print("+");
                Serial.println(trimValue);
              } else {
                Serial.println("Subtrim value must be between -90 and +90");
              }
            } else {
              Serial.println("Invalid motor number (0-7)");
            }
          }
        }
        else if (strncmp(command_buffer, "all ", 4) == 0) {
             if (sscanf(command_buffer + 4, "%d", &angle) == 1) {
                 for (int i = 0; i < 8; i++) setServoAngle(i, angle);
                 Serial.print("All servos set to "); Serial.println(angle);
             }
        }
        else if (sscanf(command_buffer, "%d %d", &motorNum, &angle) == 2) {
             if (motorNum >= 0 && motorNum < 8) {
                 setServoAngle(motorNum, angle);
                 Serial.print("Servo "); Serial.print(motorNum); Serial.print(" set to "); Serial.println(angle);
             } else {
                 Serial.println("Invalid motor number (0-7)");
             }
        }
        buffer_pos = 0;
      }
    } else if (buffer_pos < sizeof(command_buffer) - 1) {
      command_buffer[buffer_pos++] = c;
    }
  }
}

// Function to update the robot's face
void updateFaceBitmap(const unsigned char* bitmap) {
  display.clearDisplay();
  display.drawBitmap(0, 0, bitmap, 128, 64, SSD1306_WHITE);
  display.display();
}

uint8_t countFrames(const unsigned char* const* frames, uint8_t maxFrames) {
  if (frames == nullptr || frames[0] == nullptr) return 0;
  uint8_t count = 0;
  for (uint8_t i = 0; i < maxFrames; i++) {
    if (frames[i] == nullptr) break;
    count++;
  }
  return count;
}
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

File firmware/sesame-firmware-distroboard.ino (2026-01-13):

#include <WiFi.h>
#include <WebServer.h>
#include <DNSServer.h>
#include <Wire.h>
#include <ESP32Servo.h>
#include <Adafruit_GFX.h>
#include <Adafruit_SSD1306.h>

// --- Access Point Configuration ---
// This is the network the Robot will create
#define AP_SSID  "Sesame-Controller"
#define AP_PASS  "12345678" // Must be at least 8 characters

#define SCREEN_WIDTH 128
#define SCREEN_HEIGHT 64
#define OLED_RESET -1
#define OLED_I2C_ADDR 0x3C

// I2C Pins for Distro Board
#define I2C_SDA 21
#define I2C_SCL 22

// DNS Server for Captive Portal
DNSServer dnsServer;
const byte DNS_PORT = 53;

Adafruit_SSD1306 display(SCREEN_WIDTH, SCREEN_HEIGHT, &Wire, OLED_RESET);
WebServer server(80);

// Global state for animations
String currentCommand = "";

// Servo Pins for Distro Board
// ======================================================================
// Pin numbers are coorisponding to the ESP32 GPIO pins and may differ based on which board you use.
// If you are using a different board, please adjust the servoPins array accordingly.
// ======================================================================
Servo servos[8];
// Sesame Distro Board Pinout
const int servoPins[8] = {15, 2, 23, 19, 4, 16, 17, 18};

// Animation constants
int frameDelay = 100;
int walkCycles = 10;
int motorCurrentDelay = 20; // ms delay between motor movements to prevent over-current

// ======================================================================
// --- FACE BITMAPS ---
// Bitmaps for the faces are stored here, can be generated with image2cpp
// ======================================================================
const unsigned char epd_bitmap_walk [] PROGMEM = { 0x00 }; 
const unsigned char epd_bitmap_rest [] PROGMEM = { 0x00 };
const unsigned char epd_bitmap_swim [] PROGMEM = { 0x00 };
const unsigned char epd_bitmap_dance [] PROGMEM = { 0x00 };
const unsigned char epd_bitmap_wave [] PROGMEM = { 0x00 };
const unsigned char epd_bitmap_point [] PROGMEM = { 0x00 };
const unsigned char epd_bitmap_stand [] PROGMEM = { 0x00 };
const unsigned char epd_bitmap_cute [] PROGMEM = { 0x00 };
const unsigned char epd_bitmap_pushup [] PROGMEM = { 0x00 };
const unsigned char epd_bitmap_freaky [] PROGMEM = { 0x00 };
const unsigned char epd_bitmap_bow [] PROGMEM = { 0x00 };
const unsigned char epd_bitmap_worm [] PROGMEM = { 0x00 };
const unsigned char epd_bitmap_shake [] PROGMEM = { 0x00 };
const unsigned char epd_bitmap_shrug [] PROGMEM = { 0x00 };
const unsigned char epd_bitmap_dead [] PROGMEM = { 0x00 };
const unsigned char epd_bitmap_crab [] PROGMEM = { 0x00 };
const unsigned char epd_bitmap_defualt [] PROGMEM = { 0x00 };

// ======================================================================
// --- WEB INTERFACE HTML ---
// ======================================================================

const char index_html[] PROGMEM = R"rawliteral(
<!DOCTYPE HTML><html>
<head>
  <title>Robot AP Controller</title>
  <meta name="viewport" content="width=device-width, initial-scale=1">
  <style>
    body { 
      font-family: 'Segoe UI', Roboto, Helvetica, Arial, sans-serif; 
      text-align: center; 
      background-color: #121212; 
      color: #e0e0e0; 
      touch-action: manipulation; 
      margin: 0;
      padding: 20px;
    }
    h2 { 
      margin-top: 10px;
      margin-bottom: 20px; 
      color: #ffffff;
      font-size: 28px;
    }
    .grid { 
      display: grid; 
      grid-template-columns: repeat(2, 1fr); 
      gap: 15px; 
      max-width: 400px; 
      margin: 0 auto; 
      padding: 10px; 
    }
    .dpad-container { 
      display: flex; 
      justify-content: center; 
      margin: 20px 0; 
    }
    .dpad { 
      display: grid; 
      grid-template-columns: repeat(3, 90px); 
      grid-template-rows: repeat(2, 90px); 
      gap: 12px; 
    }
    .dpad button { 
      font-size: 35px; 
      background-color: #333333; 
      border: 2px solid #555555; 
      box-shadow: 0 4px #111111;
    }
    button { 
      background-color: #333333; 
      border: none; 
      color: #e0e0e0; 
      padding: 15px; 
      font-size: 18px; 
      border-radius: 12px; 
      cursor: pointer; 
      user-select: none; 
      box-shadow: 0 4px #111111;
      transition: all 0.1s;
    }
    button:active { 
      box-shadow: 0 2px #111111;
      transform: translateY(2px); 
    }
    .btn-pose { 
      background-color: #2c3e50; 
      box-shadow: 0 4px #1a252f; 
    }
    .btn-pose:active { 
      background-color: #34495e; 
      box-shadow: 0 2px #1a252f; 
    }
    .btn-stop-all { 
      background-color: #d00000; 
      width: 95%; 
      max-width: 400px; 
      margin: 30px auto; 
      display: block; 
      font-weight: bold; 
      font-size: 24px; 
      padding: 20px; 
      border-radius: 15px; 
      box-shadow: 0 6px #800000;
      border: 2px solid #ff4d4d;
      color: white;
    }
    .btn-stop-all:active { 
      box-shadow: 0 2px #800000; 
      transform: translateY(4px); 
    }
    .btn-settings { 
      background-color: #444444; 
      box-shadow: 0 4px #222222; 
      margin-top: 10px;
      padding: 10px 25px;
    }
    .spacer { visibility: hidden; }
    .settings-panel { 
      display: none; 
      position: fixed; 
      top: 0; 
      left: 0; 
      width: 100%; 
      height: 100%; 
      background: rgba(0,0,0,0.85); 
      z-index: 100; 
      backdrop-filter: blur(5px); 
    }
    .settings-content { 
      background: #1e1e1e; 
      border: 1px solid #444444; 
      max-width: 300px; 
      margin: 50px auto; 
      padding: 25px; 
      border-radius: 20px; 
      text-align: left; 
      box-shadow: 0 10px 30px rgba(0,0,0,0.5); 
    }
    .settings-content h3 { color: #ffffff; margin-top: 0; }
    .settings-content label { display: block; margin-top: 15px; font-weight: bold; color: #cccccc; }
    .settings-content input { 
      width: 100%; 
      padding: 10px; 
      margin-top: 5px; 
      background: #333333; 
      color: #fff; 
      border: 1px solid #555555; 
      border-radius: 8px; 
      box-sizing: border-box;
    }
    .btn-save { background-color: #27ae60; box-shadow: 0 4px #1e8449; width: 100%; margin-top: 25px; color: white; }
    .btn-close { background-color: #c0392b; box-shadow: 0 4px #922b21; width: 100%; margin-top: 12px; color: white; }
  </style>
</head>
<body>
  <h2>Sesame Controller</h2>
  
  <div class="dpad-container">
    <div class="dpad">
      <div class="spacer"></div>
      <button onmousedown="move('forward')" onmouseup="stop()" ontouchstart="move('forward')" ontouchend="stop()">&#9650;</button>
      <div class="spacer"></div>
      
      <button onmousedown="move('left')" onmouseup="stop()" ontouchstart="move('left')" ontouchend="stop()">&#9664;</button>
      <button onmousedown="move('backward')" onmouseup="stop()" ontouchstart="move('backward')" ontouchend="stop()">&#9660;</button>
      <button onmousedown="move('right')" onmouseup="stop()" ontouchstart="move('right')" ontouchend="stop()">&#9654;</button>
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

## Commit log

2026-01-07 Add beta firmware and assets
    Added initial firmware source files for Sesame Robot, including S2 Mini and Distro Board variants, face bitmap assets (faces.json), and placeholder assets. Updated README with detailed technical docu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
2026-01-13 Add PCB image and update servo comment
    Added pcbs.png to hardware/pcb directory. Updated a comment in the firmware to clarify servo pulse width mapping.
2026-01-13 Update PCB README
    Added a VSCode launch.json for CMake debugging and updated the hardware/PCB/README.md with minor formatting changes and improved instructions for ordering the Sesame Distro Board.
2026-01-21 Update build guide for top cover styles and add images
    Expanded the build guide to cover both Enclosed and Original top cover assembly steps, including wiring and installation instructions. Added new images for display wiring, display insertion, securing the display, and switch installation. Corrected screw specification for securing the bottom cover.
2026-01-21 Update affected STL files to v80
    [Bottom-Cover-v71.stl, Bottom-Cover-v80.stl, Interna-Frame-v71.stl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]
2026-02-03 Update misc stl to v90
    [Internal-Frame-v80.stl, bottom-cover-v90.stl, internal-frame-v90.stl]
2026-02-03 Update Enclosed top cover to v91
    Relocated mounting holes for the top cover to improve Distro Board V1 and V2 clearance (V2 coming soon)
    Cleaned up the internal mounting of the OLED display for the enclosed top cover.
    [sesame-top-cover-enclosed-v80.stl, sesame-top-cover-enclosed-v91.stl]
2026-02-03 Update top cover README version to v91
    Rename the top cover section header in hardware/printing/stl/top-covers/README.md from "Enclosed v80" to "Enclosed v91" to reflect the current modern Sesame top cover version and keep documentation c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
2026-02-03 Add WiFi info scrolling and input tracking
    Introduce a scrolling WiFi info banner on the OLED and track user input to hide it once interaction begins. Adds state variables (lastInputTime, firstInputReceived, showingWifiInfo, wifiScrollPos, wi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
2026-02-03 Update serial banner to Motor Tester Interface
    Change the printed header in firmware/debugging-firmware/sesame-motor-tester.ino
2026-02-15 Add Distro Board V2 docs and clarify build options
    Introduce and document the Sesame Distro Board V2 across the repo and clarify build paths. Updates to README files (root, docs, firmware, hardware, bom, and pcb) add V2 as the current option (pre-fla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

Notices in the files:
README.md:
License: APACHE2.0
